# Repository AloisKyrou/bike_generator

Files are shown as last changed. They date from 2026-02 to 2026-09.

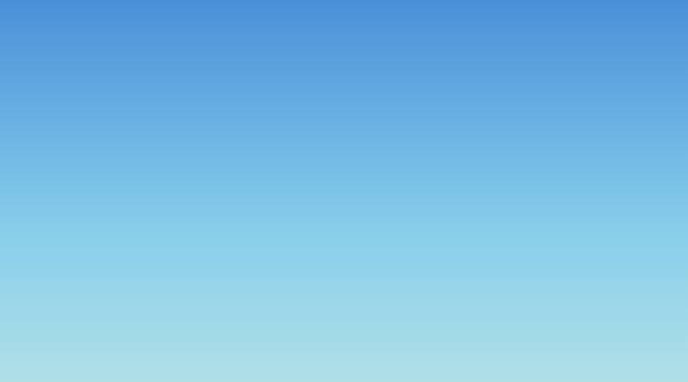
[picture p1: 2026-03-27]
webapp/bike-watts/assets/world/background.png

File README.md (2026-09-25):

# Bike Generator — Smart Trainer

> Turn a scooter motor and a stationary bike into a power-generating trainer that speaks the standard Bluetooth FTMS protocol. Control has been verified with Zwift and TrainerDay; other FTMS applications remain to be tested explicitly.

Project overview placeholder
*Photo placeholder — full system: bike, generator, electronics box, BLUETTI*

---

## What is this?

This project converts human pedaling power into usable electrical energy, while also making the bike behave like a **smart trainer** — the kind you would use with a cycling app like Zwift.

The rider pedals, a scooter motor (used as a generator) produces electricity, a DC/DC converter regulates it to 24V, and a **BLUETTI AC50S** power station charges from it.

At the same time, an **ESP32-C3** microcontroller:
- Measures voltage, current and power on the bus
- Controls pedaling resistance via a digital potentiometer on the DC/DC converter
- Exposes all of this over **Bluetooth** using the standard **FTMS protocol**, so any cycling app can connect and control the trainer

Surplus power that the BLUETTI cannot absorb is burned off by halogen lamp dump loads, which also provide a baseline braking torque.

---

## System Overview

```
[Rider] -> [Motor/Generator] -> [Rectifier] -> [DC/DC Buck 24V] -> [BLUETTI AC50S]
                                                     |
                                               [Dump Load 40-80W]
                                                     |
                                              [ESP32-C3 controller]
                                               measures V, I, P
                                               controls resistance via SPI digipot
                                               streams data over BLE (FTMS)
```

Power path diagram placeholder
*Diagram placeholder — power path schematic*

---

## Features

- **Real power generation** — energy goes into a real battery (BLUETTI AC50S, 500Wh)
- **Standard smart-trainer interface** — verified with Zwift and TrainerDay; designed for other Bluetooth FTMS clients
- **Three control modes:**
  - **Manual** — set resistance level with a physical BLE button or from the app
  - **ERG** — app sets a target wattage, mapped to a calibrated resistance setting (open loop)
  - **Simulation** — app sends road gradient, system adjusts resistance accordingly
- **Live telemetry** — voltage, current, power streamed over BLE at 2 Hz
- **Passive dump load** — permanently connected halogen lamps absorb surplus power and add baseline braking torque
- **Wireless button** — EnOcean PTM215B BLE button for standalone control (no phone needed)

---

## Hardware

| Component | Role |
|---|---|
| Scooter motor | Generator (3-phase AC) |
| 3-phase bridge rectifier | AC to DC |
| 400W CV/CC buck module | Regulated 24V bus and current limit |
| **ESP32-C3** (Beetle) | MCU: sensors, BLE, digipot control |
| **DFR0520** prototype / **MCP4151-104** PCB V1 | Digital potentiometer, sets buck current limit via SPI |
| **ACS712 30A** | Hall-effect current sensor |
| Resistive voltage divider (100k + 7.5k) | Bus voltage measurement, safe across the BLUETTI's 12–40V input range |
| **BLUETTI AC50S** | 500Wh power station, primary load |
| G4 12V/20W halogen bulbs (pairs in series) | Dump load (~40W per pair) |
| EnOcean PTM215B | BLE pushbutton for manual resistance control |

See the **[component references](docs/components/README.md)** for datasheets and product links.

---

## Electronics Box

Electronics box placeholder
*Photo placeholder — inside the electronics enclosure*

The prototype uses an external DFR0520 module. PCB V1 integrates the equivalent
single-channel MCP4151-104 and exposes only `CC_A`, `CC_W` and `CC_B` toward the
buck current-limit potentiometer terminals.

---

## Getting Started

### 1. Hardware assembly

Follow the wiring guide in **[docs/hardware.md](docs/hardware.md)**.

Key points:
- Wire the ACS712 in-line with the bus current path
- Wire the resistive divider (100k + 7.5k) from the bus to GPIO1
- Prototype: wire the DFR0520 as documented. PCB V1: connect only `J_CC_CTRL`
  after validating the buck's A/W/B voltage and current limits.
- Wire halogen pairs (2x G4 12V/20W in series) across the 24V bus

### 2. Configure config.h

Open `config.h` and confirm your values:

```cpp
#define PIN_CURRENT_SENSOR  0       // ACS712 on GPIO0
#define PIN_VOLTAGE_SENSOR  1       // voltage divider on GPIO1

#define POT_CAL_VALUE       30      // wiper position during calibration
#define POT_CAL_POWER       120.0f  // measured watts at that wiper position

#define VDIV_R1_OHMS        100000.0f
#define VDIV_R2_OHMS         7500.0f
```

### 3. Flash the firmware

- Open `bike_generator.ino` in the **Arduino IDE**
- Select board: **ESP32C3 Dev Module**
- Upload and open Serial Monitor at **115200 baud**

You should see:
```
*** READY TO PAIR ***
Device name: 'ESP32 Bike Trainer'
```

### 4. Connect a cycling app

Open Zwift (or any FTMS-compatible app), scan for **"ESP32 Bike Trainer"** and pair it as your controllable trainer and power meter.

App pairing placeholder
*Screenshot placeholder — device pairing in Zwift*

### 5. Ride

Start pedaling. The app displays your live power and controls resistance based on the virtual road. Surplus power charges the BLUETTI.

---

## Calibration

1. Apply a known voltage to the bus (e.g. bench PSU at 24.0V)
2. Read the Serial Monitor: adjust `VDIV_OFFSET_V` if the reported voltage differs from your multimeter
3. Pedal steadily at wiper `POT_CAL_VALUE = 30`, note the stable watt reading, update `POT_CAL_POWER`

Full procedure: **[docs/hardware.md](docs/hardware.md)**

---

## Documentation

| Document | Contents |
|---|---|
| **[docs/build-tutorial.md](docs/build-tutorial.md)** | **Full step-by-step build guide — start here** |
| **[electrical/](electrical/)** | **Electrical engineering workspace, component files and future KiCad project** |
| [docs/ble-api.md](docs/ble-api.md) | BLE API reference for app/game developers |
| [docs/hardware.md](docs/hardware.md) | Power path, wiring, pinout, calibration |
| [docs/electrical/](docs/electrical/) | Electrical analysis and INA228 PCB V1 design dossier |
| [docs/firmware.md](docs/firmware.md) | Code architecture, BLE FTMS, control modes |
| [docs/components/README.md](docs/components/README.md) | Datasheets and product links |
| [docs/pedaling-resistance-physics.md](docs/pedaling-resistance-physics.md) | Why electrical loading creates braking torque, operating regions, and measurement plan |
| [docs/related-projects.md](docs/related-projects.md) | Comparison with ble-ftms, SmartSpin2k, and Gymnasticon |

---

## Safety Notes

- BLUETTI DC input: **12-40V max, 10A max, 120W max** — do not exceed
- Fuse the 24V bus at **10A**
- Halogen lamps get very hot — use a ventilated non-flammable enclosure
- ACS712 must have **no current flowing at boot** for auto-calibration to work
- ESP32-C3 GPIO pins: **3.3V max**

---

## Roadmap

- [ ] Dump load MOSFET switching with soft-start ramp
- [ ] Bus voltage hysteresis loop for dump load control
- [ ] Separate current metering for BLUETTI vs dump load
- [ ] Temperature sensors on buck and rectifier
- [ ] iOS companion app for Wh session tracking

---

## License

[MIT](LICENSE)

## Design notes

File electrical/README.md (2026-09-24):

# Electrical workspace

This directory contains the engineering workspace for the electrical part of
the bike generator. It is kept separate from the firmware, web application and
public build documentation at the repository root.

The KiCad 10 project has been created through Konnect under
[`kicad/bike-generator-controller/`](kicad/bike-generator-controller/). Its
five-sheet functional hierarchy is in place; the component-level design is now
implemented for measurement, control, MCU and low-voltage connectors. The
power path remains deliberately open until its electrical limits are measured.

## Directory map

```text
electrical/
├── components/                 Component references and downloaded datasheets
├── measurements/               Raw measurements, photos and processed results
├── bom/                        Working bills of materials and sourcing notes
└── kicad/
    ├── bike-generator-controller/  KiCad project sources
    ├── libraries/                  Project-owned symbols, footprints and 3D models
    └── exports/                    Generated review/fabrication outputs
```

## Existing design documentation

The current analysis remains in [`docs/electrical/`](../docs/electrical/) so it
stays visible from the main project documentation:

- [Electrical decisions and scope](../docs/electrical/README.md)
- [Observed prototype and open questions](../docs/electrical/as-built-and-open-questions.md)
- [INA228 PCB V1 specification](../docs/electrical/pcb-v1-ina228.md)
- [Measurement campaign](../docs/electrical/measurement-campaign.md)
- [Design methodologies](../docs/electrical/design-methodologies.md)
- [KiCad workflow and troubleshooting](kicad/WORKFLOW.md)
- [Controller V1 working BOM](bom/controller-v1-working.md)

## Working rules

- Component PDFs and manufacturer files belong in `components/`, not beside the
  KiCad sources.
- Raw readings are never overwritten; corrected or transformed data goes into
  `measurements/processed/`.
- Generated Gerbers, PDFs and manufacturing archives belong in
  `kicad/exports/` and are ignored by Git by default.
- KiCad sources will be versioned, but must only be created or changed through
  KiCad/Konnect to preserve their internal references.

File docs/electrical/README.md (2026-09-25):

# Dossier électrique et PCB

Ce dossier rassemble l'état des connaissances électriques du vélo générateur et
prépare une première carte électronique sous KiCad.

Les fichiers de travail, datasheets, mesures et le futur projet KiCad sont
rangés dans l'[espace d'ingénierie électrique](../../electrical/).

Il distingue volontairement :

- le prototype actuellement assemblé sur breadboard ;
- les éléments identifiés mais encore à mesurer ;
- la cible décidée pour le PCB V1 ;
- les améliorations reportées à une révision ultérieure.

## Décision actuelle pour le PCB V1

La première carte utilisera un **INA228AIDGSR soudé directement sur le PCB** avec
une résistance shunt dédiée. Elle ne conservera pas l'ACS712 et le pont diviseur
comme chaîne de mesure principale.

Décisions retenues :

- CAO : KiCad ;
- microcontrôleur : carte DFRobot Beetle ESP32-C3 DFR0868 montée sur connecteurs ;
- mesure : INA228, interface I2C, alimentation logique 3,3 V ;
- shunt V1 : Bourns `CSS4J-4026K-2L00F`, 2 mΩ, quatre bornes, 6 W, avec
  footprint KiCad natif géométriquement compatible ;
- emplacement : conducteur positif, après le redresseur et avant le buck ;
- grandeur mesurée : puissance électrique envoyée par la génératrice au buck ;
- enveloppe de puissance : 400 W, avec 20 A continus et 25 A transitoires comme
  base préliminaire de dimensionnement du chemin cuivre ;
- convertisseur 400 W : conservé comme module externe ;
- sortie du convertisseur principal : 24 V réglé manuellement ; batterie ou
  charge aval laissée hors du périmètre du PCB contrôleur ;
- alimentation autonome : branche auxiliaire prélevée après fusible et shunt,
  avant le buck principal ;
- convertisseur auxiliaire : LM5164 100 V / 1 A pour une sortie 5 V, composants
  périphériques V1 sélectionnés et calcul documenté ;
- batterie contrôleur : LiPo 1S protégée `801350`, 500 mAh, raccordée à la
  broche `BAT` du Beetle par JST-PH ;
- sélection de source : interrupteur batterie et cavalier `JP_GEN_5V` pour
  isoler l'alimentation générateur pendant l'usage USB ;
- commande CC : `MCP4151-104E/SN` simple canal intégré au PCB, après validation
  électrique de l'interface du buck ;
- interface principale : BLE ;
- interface locale : voyants et connecteur I2C pour un écran optionnel ;
- écran : non imposé et non soudé directement sur la V1.

La valeur mesurée avant le buck n'est pas exactement la puissance mécanique aux
pédales. Elle exclut les pertes mécaniques, celles de la génératrice et celles du
redresseur. Elle est toutefois mieux corrélée à l'effort produit que la seule
puissance livrée à la batterie après conversion.

## Ce qui ne fait pas partie de la V1

- recréer le convertisseur CV/CC 400 W sur le PCB ;
- intégrer les composants de puissance du buck ;
- intégrer ou gérer la batterie principale située après la sortie 24 V ;
- réaliser un compteur certifié d'énergie ;
- garantir une estimation exacte de la puissance mécanique du cycliste ;
- intégrer immédiatement un écran couleur ;
- commuter automatiquement les charges de dissipation.

## Documents

| Document | Contenu |
|---|---|
| [État actuel et questions ouvertes](as-built-and-open-questions.md) | Lecture des photos, références probables, incohérences et risques |
| [Spécification du PCB V1](pcb-v1-ina228.md) | Architecture cible, INA228, shunt, connecteurs et coût indicatif |
| [Campagne de mesures](measurement-campaign.md) | Relevés nécessaires avant de figer le schéma |
| [Dimensionnement du chemin de puissance](power-path-dimensioning.md) | Interprétation des mesures, commande CC, composants candidats, batterie et intégration mécanique |
| [Méthodologies de conception](design-methodologies.md) | Manières possibles de démarrer et méthode hybride recommandée |

## Statuts employés

- **observé** : visible sur une photo ou mesuré physiquement ;
- **documenté** : présent dans le code ou un document du dépôt ;
- **probable** : identification forte, mais référence à confirmer ;
- **décidé pour V1** : choix de conception, pas encore réalisé ;
- **bloquant** : information requise avant fabrication.

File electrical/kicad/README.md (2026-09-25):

# KiCad workspace

The KiCad 10 project lives at:

```text
electrical/kicad/bike-generator-controller/
```

The planned project basename is:

```text
bike-generator-controller
```

The project was created and edited through Konnect. It contains the root
schematic, six hierarchical sheets and the initial PCB file for KiCad 10.0:

- `bike-generator-controller.kicad_pro`
- `bike-generator-controller.kicad_sch`
- `bike-generator-controller.kicad_pcb`

## Layout

```text
kicad/
├── bike-generator-controller/  Project sources created by KiCad/Konnect
├── libraries/
│   ├── symbols/                 Project-owned custom symbol libraries
│   ├── footprints/              Project-owned `.pretty` libraries
│   └── 3d-models/               STEP/WRL models owned by the project
└── exports/                     Generated PDFs, Gerbers, drills, BOM and CPL
```

Manufacturer PDFs do not belong here; store them under
[`../components/`](../components/).

## Schematic sheets

The initial schematic hierarchy has been created:

1. `POWER_PATH`
2. `INA228_SENSE`
3. `MCU`
4. `CC_CONTROL`
5. `CONNECTORS`
6. `AUX_SUPPLY`

The root schematic contains these six sheets on pages 2 to 7. `INA228_SENSE`,
`MCU`, `CC_CONTROL`, `CONNECTORS`, `POWER_PATH` and `AUX_SUPPLY` are populated
and linked. `POWER_PATH` contains the 400 W path, the provisional four-wire
shunt, `BUS_PROTECTED`, the external buck connection and the separately fused
auxiliary branch. Its Kelvin and bus outputs feed `INA228_SENSE`, while
`AUX_IN_PROTECTED` feeds the LM5164 sheet.

`AUX_SUPPLY` implements the 5 V supply around the LM5164 for the V1 protected
bus ceiling of 80 V, including UVLO, feedback, Type-3 ripple network,
input/output capacitors, `PGOOD`, a power flag and four test points. Its V1
passives and footprints are selected. The MLCC DC-bias curves are checked;
`C4`, `C5` and the added parallel `C13` are now the selected 10 µF / 100 V
X7S parts in KiCad. The TI/WEBENCH cross-check remains required before ordering.
`AUX_5V` is now connected to the MCU sheet through the manual `JP3`
generator/USB interlock. The global ERC reports exactly one intentional error:
the root-sheet output `AUX_PGOOD` is not yet connected to the future hardware
enable logic. It must not be waived or hidden.

The MCU sheet now assigns two existing KiCad footprints, both still marked
provisional: a 2.54 mm through-hole 1x02 header for `JP3`, and
`Connector_JST:JST_PH_S2B-PH-K_1x02_P2.00mm_Horizontal` for the battery
connector `J6`. `J6.1` is `BAT_RAW` and `J6.2` is `GND`. The real battery plug
pitch, mating orientation and polarity must be checked before PCB release.

Project-owned library items currently include:

- `BikeGenerator:DFR0868_Beetle_ESP32-C3` — symbole de schéma ;
- `BikeGenerator:DFR0868_Beetle_ESP32-C3_V2_Socketed` — empreinte porte-module
  sur deux sockets 1×8, créée depuis le CAD DFRobot V2.0 et affectée à `U2` ;
- `BikeGenerator:DFR0520_Dual_Digital_Pot` — ancien module traversant conservé
  uniquement pour documenter le prototype ; le PCB V1 utilise les bibliothèques
  KiCad natives pour `MCP4151-104E/SN` et son SOIC-8.

See the [KiCad workflow and troubleshooting guide](WORKFLOW.md) for the
creation steps, their manual equivalent and the verification process.
The implementation order and completion gates are tracked in the
[KiCad roadmap](ROADMAP.md).
The latest project-level connectivity evidence is summarized in
[the connection audit](CONNECTION_AUDIT.md).
The active PCB routing classes, their net assignments and their engineering
limits are recorded in [NETCLASSES.md](NETCLASSES.md).

## Source and generated files

Version in Git:

- KiCad project, schematic and PCB sources;
- project-local library tables and custom libraries;
- explicit design-rule files;
- human-written design notes.

Keep outside Git by default:

- lock, autosave and backup files;
- temporary plots;
- generated fabrication outputs under `exports/`.

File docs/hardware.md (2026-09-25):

# Hardware Reference

This document covers the full power path, wiring, pinout and calibration procedure for the bike generator system.

> This page describes the current ACS712-based prototype. The planned KiCad PCB
> V1 replaces the ACS712 and voltage-divider measurement chain with an INA228 and
> a shunt placed before the buck. See the [electrical and PCB dossier](electrical/).

---

## 1. Power Path Overview

```
[Rider pedaling]
      │
      ▼
[Scooter motor used as generator — 3-phase AC]
      │
      ▼
[3-phase bridge rectifier — DC output]
      │
      ▼
[DC/DC Buck module — CV/CC 400W class]
  Sets regulated 24V bus + current limit (= pedaling resistance)
  Current limit driven by DFR0520 (prototype) or MCP4151-104 (PCB V1) via SPI
      │
      ├──────────────────────────────┐
      ▼                              ▼
[BLUETTI AC50S DC input]     [Dump load — halogen lamps G4 12V/20W]
  Up to ~120W charging          Surplus power + baseline braking torque
```

The DC bus nominally runs at **24V**. The BLUETTI is the primary sink (up to ~120W / ~5A). Halogen lamps on the bus act as a permanent dump load to absorb excess power and provide baseline braking torque even when the BLUETTI is not charging.

---

## 2. Component Map & Pinout

### ESP32-C3 (Beetle variant)

| GPIO | Function | Notes |
|---|---|---|
| 0 | ACS712 current sensor (ADC) | `ADC_11db`, 12-bit |
| 1 | Voltage divider (ADC) | `ADC_11db`, 12-bit |
| 4 | Free / extension | No longer used by the PCB V1 digipot |
| 5 | MCP4151 CS | Chip Select, active LOW |
| 6 | MCP4151 SCK | SPI clock |
| 7 | MCP4151 SDI/SDO | Write-only SPI data in PCB V1 |

> ⚠️ ESP32-C3 ADC pins are 3.3V max. Never exceed this voltage on any ADC input.

---

## 3. Current Sensing — ACS712 30A

The ACS712 outputs a voltage proportional to current, centered at Vcc/2 (~1.65V at 3.3V supply) with no current flowing.

**Calibration formula:**
```
I (A) = |V_adc - V_midpoint| / sensitivity
```

- `sensitivity` = 39 mV/A (calibrated; nominal for 30A variant is 66 mV/A — adjust in `config.h`)
- `V_midpoint` is measured at boot with no current flowing (auto-calibration in `Sensors_Calibrate()`)

**Wiring:**
```
Bus current path ──► [IP+] ACS712 [IP-] ──► load
                          │
                        [VIOUT] ──► GPIO0 (ADC)
                        [VCC]  ──► 3.3V
                        [GND]  ──► GND
```

> ⚠️ At boot, make sure no current is flowing through the ACS712. The firmware takes a zero-current baseline for ~1 second during `setup()`.

---

## 4. Voltage Sensing — Resistive Divider

To measure the ~24V bus with the 3.3V ADC, a resistive divider scales the voltage down.

**Circuit:**
```
V_BUS ──[R1 = 100kΩ]──┬──[R2 = 7.5kΩ]── GND
                       └──► GPIO1 (ADC)
```

**Scaling:**
```
V_ADC = V_BUS × R2 / (R1 + R2)
      = V_BUS × 7.5k / 107.5k
      = V_BUS × 0.0698

V_BUS (theoretical ADC limit) = 3.3V / 0.0698 ≈ 47.3V
At the BLUETTI 40V input ceiling, the ADC sees about 2.79V.
```

**To change resistor values:** only edit `VDIV_R1_OHMS` and `VDIV_R2_OHMS` in `config.h`. The scale factor and max voltage are derived automatically.

**Software calibration trim:** after wiring, measure a known voltage on the bus with a multimeter and compare to the serial log output `ADC volt: Vpin=X.XXV → bus=XX.XXV`. Adjust `VDIV_OFFSET_V` by the difference.

---

## 5. Digital Potentiometer — MCP4151-104 (PCB V1)

The breadboard prototype used a DFR0520 breakout containing a dual MCP42100.
PCB V1 replaces it with one `MCP4151-104E/SN`: one 100kΩ channel, 257
positions and a native SOIC-8 footprint. The external `CC_A`, `CC_W` and
`CC_B` behavior remains unchanged.

The single channel is wired into the buck module's CC (constant current)
feedback network. Moving the wiper changes the current limit setpoint and thus
how hard the rider must pedal.

**SPI protocol:**
```
CS LOW → send 0x00 (write volatile wiper 0) → send value (0–255) → CS HIGH
```

The analog compatibility gate remains mandatory: before connecting the buck,
verify that A/W/B always remain between 0 and 3.3V and below 2.5mA.

**Wiper-to-power mapping (linear, single-point calibrated):**
```
wiper = target_power × (POT_CAL_VALUE / POT_CAL_POWER)
      = target_power × (30 / 120)
      = target_power / 4
```

Update `POT_CAL_VALUE` and `POT_CAL_POWER` in `config.h` after measuring your actual system.

**Safe operating ceiling:** `POT_SAFE_MAX = HILL_POWER_TARGET / 4 = 50`. The wiper is never sent above this value, capping bus power at 200W (120W BLUETTI + 2×40W halogen).

---

## 6. Dump Load — G4 Halogen Lamps

**Configuration:** pairs of G4 12V/20W bulbs wired **in series** across the 24V bus.

```
24V bus ──[bulb A 12V/20W]──[bulb B 12V/20W]── GND
```

Each pair dissipates ~40W at 24V (once filaments are hot). Multiple pairs can be wired in parallel to increase dump power in ~40W steps.

| Pairs | Dump power |
|---|---|
| 1 | ~40W |
| 2 | ~80W |
| 3 | ~120W |

> ⚠️ Cold filament resistance is much lower than hot — expect inrush current spikes when switching lamps. The lamps get very hot; ensure ventilation and keep away from plastics.

---

## 7. BLUETTI AC50S DC Input

- Input range: **12–40V OCV**
- Max current: **10A**
- Max power: **120W**

At 24V, the BLUETTI will absorb up to ~5A. If the generator produces more than 120W, the surplus must go to the dump load to prevent bus overvoltage.

**DC input connector:** XT60 or barrel (check your unit). Wire bus positive/negative with correct polarity — there is no reverse polarity protection on the BLUETTI input.

---

## 8. Wiring Safety Checklist

- [ ] Fuse the bus at 10A (protects BLUETTI and wiring)
- [ ] ACS712 in the current path — rated 30A, continuous
- [ ] Resistor divider: R1/R2 must be rated for the voltage (standard ¼W fine for voltage sensing only)
- [ ] Halogen lamps: mounted on ceramic/metal base, ventilated enclosure
- [ ] Buck module: heatsink + airflow for sustained operation
- [ ] All high-current connections: short, thick wire (≥ 1.5mm² / AWG14 for bus)
- [ ] ESP32-C3 powered from 3.3V regulated supply — not directly from 24V bus

---

## 9. Calibration Procedure (First Boot)

1. **Do not connect the bus / generator yet.**
2. Flash the firmware, open Serial Monitor at 115200 baud.
3. Power the ESP32-C3 from USB only. Observe the ACS712 midpoint calibration log:
   ```
   [SENSORS] ACS712 midpoint: 1650 mV (1.650V)
   ```
4. Connect the voltage divider to a known reference (e.g. bench PSU at 24.0V).
5. Observe the serial log:
   ```
   ADC volt: Vpin=1.674V → bus=24.0V (divider x14.33)
   ```
   If the bus reading differs from your multimeter, adjust `VDIV_OFFSET_V` in `config.h`.
6. Connect the full system and verify power readings at a steady pedaling effort.
7. Update `POT_CAL_VALUE` and `POT_CAL_POWER` in `config.h` with your measured wiper/power pair.

---

*See also: [Firmware Architecture](firmware.md) · [Component References](components/)*

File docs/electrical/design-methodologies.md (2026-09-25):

# Méthodologies possibles pour démarrer le PCB

Plusieurs méthodes sont raisonnables. Elles diffèrent surtout par la quantité de
mesures effectuées avant le premier schéma et par le risque accepté sur la
première fabrication.

## Méthode A — recopier et fiabiliser le prototype

1. Relever fil par fil la breadboard.
2. Dessiner le schéma « tel que construit ».
3. Remplacer ACS712 et pont diviseur par INA228 + shunt.
4. Ajouter connecteurs, protections et points de test.
5. Router puis fabriquer.

**Atout :** passage très direct du montage qui fonctionne vers une carte.

**Limite :** les erreurs et hypothèses implicites du prototype risquent d'être
reproduites. L'interface CC à deux fils doit impérativement être comprise avant
le routage.

## Méthode B — partir des exigences et des fiches techniques

1. Fixer tensions, courants, température, environnement et état sûr.
2. Dessiner l'architecture fonctionnelle cible.
3. Concevoir chaque sous-circuit depuis la fiche de son fabricant.
4. Définir les interfaces avec le buck et les modules existants.
5. Vérifier le résultat sur le prototype avant fabrication.

**Atout :** schéma plus propre, justifiable et reproductible.

**Limite :** risque de concevoir autour de valeurs théoriques qui ne décrivent
pas parfaitement le matériel déjà possédé.

## Méthode C — tester d'abord le INA228 sur une carte d'évaluation

1. Acheter ou assembler un petit module INA228.
2. Le connecter temporairement avant le buck avec un shunt adapté.
3. Valider les lectures I2C et comparer avec le multimètre.
4. Copier le sous-circuit validé dans le PCB définitif.

**Atout :** réduit fortement le risque lié au capteur et permet d'écrire le
pilote avant la réception du PCB.

**Limite :** coût et étape supplémentaires ; les performances du module ne
garantissent pas celles du routage final.

## Méthode D — carte porte-modules minimale

1. Conserver le Beetle sur connecteurs et intégrer le MCP4151 simple canal.
2. Intégrer INA228, shunt, alimentation, protections et connectique.
3. Garder le buck, le redresseur et les charges externes.
4. Prévoir beaucoup de points de test et d'options non montées.

**Atout :** excellente première carte : utile, réparable et d'une complexité
raisonnable.

**Limite :** moins compacte qu'une intégration complète et dépend encore des
modules du commerce.

## Méthode recommandée — hybride par jalons

La meilleure approche pour ce projet combine B, C et D :

### Jalon 1 — caractériser

- effectuer la campagne de mesures ;
- figer tension maximale, courant cible et stratégie de masse ;
- caractériser précisément le réglage CC.

**Sortie :** tableau de mesures complet et aucune interface électrique inconnue.

### Jalon 2 — schéma fonctionnel KiCad

- créer les feuilles `POWER_PATH`, `INA228_SENSE`, `MCU`, `CC_CONTROL` et
  `CONNECTORS` ; le bloc auxiliaire LM5164 reste dans `POWER_PATH` pour garder
  l'origine de son énergie et les protections de bus sur une même feuille ;
- représenter le buck et le redresseur comme blocs externes connectés ;
- inscrire sur le schéma les limites de tension et courant de chaque liaison.

**Sortie :** schéma lisible indépendamment du PCB et nomenclature préliminaire.

### Jalon 3 — preuve de mesure

- tester un INA228 sur module d'évaluation si disponible, ou réaliser d'abord le
  sous-circuit sur une petite carte d'essai ;
- écrire un pilote minimal : identité, tension, courant, puissance et alerte ;
- comparer avec un multimètre et une charge connue.

**Sortie :** valeurs cohérentes et constante de shunt validée.

### Jalon 4 — schéma électrique complet

- intégrer l'alimentation auxiliaire LM5164, la batterie contrôleur,
  `JP_GEN_5V`, les protections, INA228, Beetle, MCP4151 et connecteurs ;
- définir l'état sûr au reset ;
- exécuter l'ERC et justifier explicitement chaque exception.

**Sortie :** revue de schéma validée avant tout routage.

### Jalon 5 — placement et routage

- placer d'abord shunt, connecteurs de puissance et INA228 ;
- router la puissance puis les paires Kelvin ;
- séparer les retours bruyants du buck de la mesure ;
- placer découplages et protections au plus près ;
- terminer par SPI, I2C, voyants et écran optionnel.

**Sortie :** DRC propre, analyse thermique et contrôle des largeurs de piste.

### Jalon 6 — fabrication et bring-up

1. vérifier les courts-circuits sans composants de puissance connectés ;
2. alimenter la logique avec une alimentation limitée en courant ;
3. vérifier 3,3 V et communication I2C ;
4. injecter 10 V sur l'entrée auxiliaire, vérifier 5 V, `PGOOD` et l'absence de
   retour de courant ;
5. valider la bascule entre alimentation générateur et batterie ;
6. tester avec une charge limitée ;
7. intégrer progressivement redresseur, buck, charges puis stockage externe.

**Sortie :** rapport de bring-up et liste des corrections pour V1.1.

## Pourquoi cette méthode convient ici

Elle permet d'apprendre une vraie conception électronique — schéma, composants
CMS, mesure analogique, puissance, implantation et firmware — sans faire du
convertisseur 400 W lui-même le premier exercice. Les modules qui fonctionnent
déjà restent remplaçables, tandis que la partie nouvelle et structurante,
l'INA228 et son shunt, est réellement intégrée au PCB.

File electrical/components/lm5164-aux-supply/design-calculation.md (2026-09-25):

# Pré-dimensionnement LM5164 — bus protégé jusqu'à 80 V vers 5 V

Statut : **base de calcul pour le schéma, pas encore une nomenclature prête à
commander**.

Ce document applique les équations de la fiche TI `SNVSAU4D`, révision D de
février 2026, archivée dans ce dossier. Les numéros de pages ci-dessous sont les
pages du PDF.

## Hypothèses V1

| Paramètre | Valeur de calcul | Commentaire |
|---|---:|---|
| Plage vérifiée | 10 à 80 V DC | bus protégé ; démarrage UVLO nominal vers 9 V |
| Plafond de bus | 80 V DC continu, transitoires tolérés compris | fonctionnement durable au-dessus hors spécification |
| Sortie | 5 V | vers l'entrée 5 V du contrôleur |
| Charge continue attendue | 600 mA | ESP32, capteurs et recharge de la batterie |
| Charge de dimensionnement | 1 A | marge pour recharge et pointes radio |
| Fréquence visée | environ 300 kHz | compromis taille, rendement et pertes |
| Ondulation d'inductance visée | environ 30 % à 50 % à 1 A | recommandation TI |
| Méthode d'injection d'ondulation | type 3 | faible ondulation de sortie |

La tension nominale réelle du bus dépendra de la vitesse de pédalage. Les
calculs sont donc vérifiés à 10, 24, 36, 60 et 80 V plutôt qu'à un seul point.

## Valeurs V1 et choix encore ouverts

| Fonction | Valeur / référence | Statut |
|---|---:|---|
| `RRON` | Yageo `RC1206FR-0741K2L`, 41,2 kΩ, 1 %, 250 mW | choix V1 figé |
| `L` | Coilcraft `MSS1038-473MLC`, 47 µH ±20 % | choix V1 validé |
| `RFB1` haut | Yageo `RT0805BRD07316KL`, 316 kΩ, 0,1 % | choix V1 figé |
| `RFB2` bas | Yageo `RT0805BRD07100KL`, 100 kΩ, 0,1 % | choix V1 figé |
| `RA` | Yageo `RC0805FR-07200KL`, 200 kΩ, 1 % | choix V1 figé |
| `CA` | Yageo `CC0805KRX7R9BB332`, 3,3 nF, 50 V, X7R | choix V1 figé |
| `CB` | Yageo `CC0805JRNPO9BN820`, 82 pF, 50 V, C0G/NP0 | choix V1 figé |
| `CBST` | Yageo `CC0805KRX7R9BB222`, 2,2 nF, 50 V, X7R | choix V1 figé |
| `COUT` | 2 × Samsung `CL32B226KOJNNNE`, 22 µF, 16 V, X7R | choix V1 figé ; environ 33,7 µF effectifs au total à 5 V et 25 °C |
| `CIN` HF | 3 × Samsung `CL32Y106KCVZ4NE`, 10 µF, 100 V, X7S | choix V1 corrigé après lecture de la courbe DC-bias à 80 V |
| `CIN` amortissement | environ 10 µF électrolytique, tension adaptée | candidat si câblage d'entrée long |
| `RUV1` | Yageo `RC0805FR-071ML`, 1 MΩ, 1 % | choix V1 figé |
| `RUV2` | Yageo `RC0805FR-07200KL`, 200 kΩ, 1 % | choix V1 figé |
| Pull-up `PGOOD` | Yageo `RC0805FR-0747KL`, 47 kΩ, 1 % | choix V1 figé |

`F_AUX` est figé à 1 A / 125 V. Seule la TVS reste source-spécifique et dépend
des mesures de la génératrice.
Le condensateur d'amortissement est le Panasonic `EEU-FC2A100`, 10 µF / 100 V.

## Fréquence et résistance `RON`

La fiche TI donne, équations 12 et 15, page PDF 17 :

```text
RRON[kΩ] = VOUT[V] × 2500 / FSW[kHz]
```

Pour 5 V et 300 kHz, la valeur théorique est 41,67 kΩ. La valeur E96 de
41,2 kΩ donne environ 303 kHz. La durée de conduction calculée avec l'équation
11 reste comprise entre 1,648 µs à 10 V et 0,206 µs à 80 V, très au-dessus du
minimum contrôlable de 50 ns.

À 80 V, la résistance voit environ 79 V puisque la broche RON est voisine de
1 V. Sa dissipation est donc d'environ 151 mW. Le passage du boîtier 0805
125 mW au `RC1206FR-0741K2L` 250 mW est nécessaire ; il laisse environ 40 % de
marge à température ambiante. Le déclassement thermique devra encore être
contrôlé avec la température réelle de la carte.

## Inductance

Les équations 18 à 20, page PDF 18, donnent :

```text
ΔIL = VOUT / (FSW × L) × (1 − VOUT / VIN)
IL_peak = IOUT_max + ΔIL / 2
```

Avec 47 µH et un calcul conservateur à 300 kHz :

| `VIN` | `tON` | `ΔIL` | Pic à 1 A |
|---:|---:|---:|---:|
| 10 V | 1,648 µs | 0,177 A | 1,089 A |
| 24 V | 0,687 µs | 0,281 A | 1,140 A |
| 36 V | 0,458 µs | 0,305 A | 1,153 A |
| 60 V | 0,275 µs | 0,325 A | 1,163 A |
| 80 V | 0,206 µs | 0,332 A | 1,166 A |

La limite de courant de crête minimale spécifiée est 1,25 A et sa valeur
maximale 1,75 A, page PDF 6. Une inductance de 47 µH conserve plus de marge
qu'une 33 ou 39 µH lorsque sa tolérance et sa baisse à chaud sont prises en
compte. La référence V1 retenue est la Coilcraft `MSS1038-473MLC` : DCR maximale
128 mΩ, courant de saturation 1,6 A à −10 %, 1,98 A à −20 % et 2,22 A à −30 %,
et courant thermique 1,45 A pour une élévation de 20 °C. Elle couvre donc le
pic calculé de 1,166 A et reste exploitable face à la limite haute de 1,75 A du
LM5164.

Critères conservés pour une éventuelle substitution :

- courant de saturation supérieur à 1,75 A, avec une préférence autour de 2 A
  ou davantage ;
- courant thermique efficace compatible avec 1 A continu ;
- valeur encore suffisante à chaud et sous courant ;
- pertes cuivre et noyau vérifiées vers 300 kHz.

L'empreinte standard retenue est
`Inductor_SMD:L_Coilcraft_MSS1038-XXX`. La Bourns `SRP1038C-470M`, également
couverte par une empreinte KiCad standard, reste une option de réduction de
coût à réévaluer, mais son statut « not recommended for new designs » empêche
de la retenir comme référence V1.

## Retour 5 V

L'équation 10, page PDF 12, donne :

```text
RFB2 = 1,2 V / (VOUT − 1,2 V) × RFB1
```

Avec `RFB1 = 316 kΩ` entre la sortie et FB et `RFB2 = 100 kΩ` entre FB et GND,
la consigne nominale vaut 4,992 V. En combinant les limites de la référence
interne TI et les tolérances des résistances :

- résistances 1 % : environ 4,839 à 5,145 V ;
- résistances 0,1 % : environ 4,906 à 5,075 V.

Le 0,1 % est donc préféré. La compatibilité de cette plage avec l'entrée 5 V et
le chargeur du Beetle doit encore être confirmée sur le schéma exact de sa
révision.

## Réseau d'ondulation type 3

Le LM5164 utilise une commande COT et demande une ondulation en phase d'au
moins 20 mV au point typique, avec au moins 12 mV à l'entrée minimale. Les
équations 24 à 26 sont détaillées pages PDF 18 et 19.

Avec `RFB1 = 316 kΩ`, `RFB2 = 100 kΩ` et 300 kHz :

- la capacité `CA` minimale calculée est environ 439 pF ;
- `CA = 3,3 nF` maintient `RA` dans une plage pratique ;
- `RA = 200 kΩ` donne environ 12,5 mV à 10 V, 19,8 mV à 24 V et
  22,9 mV à 60 V, puis 23,4 mV à 80 V ;
- pour un objectif de stabilisation de 75 µs, `CB` calculé vaut environ 79 pF,
  d'où la valeur standard 82 pF en C0G/NP0.

Ces valeurs doivent encore être vérifiées dans le calculateur LM5164 de TI et
sur prototype. Le nœud FB devra rester très court et éloigné de `SW`.

## Condensateurs

### Sortie

L'équation 21 limite l'ondulation capacitive à 0,5 % de 5 V, soit 25 mV. Avec
47 µH, la capacité effective minimale calculée varie d'environ 3,0 µF à 10 V
d'entrée à 5,5 µF à 80 V. La courbe Samsung indique −23,41 % à 5 V : deux
condensateurs de 22 µF donnent environ 33,7 µF effectifs au total à 25 °C,
avant tolérance et température. La marge reste très supérieure au minimum
calculé.

### Entrée

TI impose au moins 2,2 µF de céramique haute fréquence près de VIN et GND.
Les deux MLCC initialement choisis (`CL32B225KCJSNNE`, 2,2 µF / 100 V) ne sont
pas conservés : la courbe Samsung indique −76,58 % à 80 V, soit seulement
1,03 µF effectif au total. La V1 emploie trois `CL32Y106KCVZ4NE`, 10 µF /
100 V, X7S. La courbe fabricant indique −86,06 % à 80 V, soit environ 4,18 µF
pour trois pièces à 25 °C. Après une estimation conservatrice ajoutant la
tolérance −10 % et la variation X7S −22 %, il reste environ 2,94 µF, au-dessus
du minimum TI de 2,2 µF. Les données brutes sont archivées dans
`../controller-passives-v1/` ; cette estimation devra encore être confirmée
sur prototype. La protection doit empêcher que les transitoires tolérés
dépassent eux aussi le plafond de 80 V ; une simple TVS parallèle ne peut pas
le garantir universellement avec seulement 5 V de marge jusqu'à l'INA228.

La fiche recommande aussi environ 10 µF électrolytique avec ESR modéré lorsque
la source est éloignée de plus de 5 cm, afin d'amortir la résonance formée par
les câbles et les céramiques. Le vélo entre clairement dans ce cas probable.

## Démarrage `EN/UVLO`

Les équations 13 et 14, page PDF 14, donnent les seuils de démarrage et d'arrêt.
Avec `RUV1 = 1 MΩ` et `RUV2 = 200 kΩ` :

- démarrage nominal : 9,0 V ;
- arrêt nominal : 8,4 V ;
- avec seuils TI et résistances 1 %, démarrage approximatif entre 8,56 et
  9,46 V, arrêt entre 7,97 et 8,79 V.

Le convertisseur est ainsi démarré avant 10 V dans le pire cas estimé, tout en
restant au-dessus de sa limite fonctionnelle minimale de 6 V. Ce choix devra
être testé sur une montée lente de la génératrice pour vérifier l'absence de
cycles marche/arrêt gênants.

## Contraintes de placement à reporter au PCB

- `CIN` au plus près des pins VIN, GND et du pad exposé ;
- boucle `VIN → MOSFET interne → SW → retour CIN` minimale ;
- `CBST` directement entre BST et SW ;
- inductance collée au nœud SW, avec surface SW minimale ;
- `RRON`, diviseur FB et réseau type 3 proches du circuit ;
- masse analogique des réseaux FB, RON et UVLO ramenée sans courant commuté ;
- pad exposé 9 relié à GND avec la variante locale V1 à six vias thermiques
  Ø0,60/0,30 mm ; anneau de 0,15 mm et traitement des vias sous pad à confirmer
  avec le fabricant ;
- éloigner les pistes Kelvin INA228, l'antenne ESP32 et les signaux numériques
  du nœud SW.

## Vérifications avant placement définitif

1. Rejouer le calcul avec le calculateur officiel LM5164 ou WEBENCH.
2. Les références de CIN, COUT, C6, des résistances et de L1 sont figées pour
   la V1.
3. Vérifier courant d'ondulation, saturation et pertes ; les capacités
   effectives des MLCC sont désormais calculées depuis les courbes Samsung.
4. Mesurer les pics, leur durée et l'impédance de source, puis choisir la TVS
   spécifique à cette source et confirmer `F_AUX`.
5. Confirmer le schéma d'alimentation interne du Beetle et l'absence de retour
   vers l'USB.
6. Prototyper avec une alimentation de laboratoire limitée en courant avant la
   génératrice.

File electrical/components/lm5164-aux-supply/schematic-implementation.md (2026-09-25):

# LM5164 — première implémentation schématique

Date de contrôle : 24 septembre 2026.

Cette note décrit l'état réellement enregistré dans la feuille KiCad
`electrical/kicad/bike-generator-controller/aux_supply.kicad_sch`. Il s'agit
d'une première passe calculée et vérifiable, pas encore d'une nomenclature de
fabrication.

## Interface de la feuille

| Signal | Direction | Rôle |
|---|---|---|
| `AUX_IN_PROTECTED` | entrée | Bus redressé protégé provenant de `POWER_PATH` |
| `AUX_5V` | sortie | Alimentation 5 V auxiliaire |
| `AUX_PGOOD` | sortie | Indication power-good du LM5164 |

La branche d'entrée porte un `PWR_FLAG` parce que la source est externe à la
feuille. `AUX_5V` est maintenant raccordé à la feuille `MCU` ; `AUX_PGOOD`
reste volontairement sans consommateur jusqu'à la conception du verrouillage
matériel de la commande CC.

## Brochage de U4 relu dans la netlist

| Broche | Nom TI | Net KiCad |
|---:|---|---|
| 1 | GND | `GND` |
| 2 | VIN | `AUX_IN_PROTECTED` |
| 3 | EN/UVLO | `UVLO` |
| 4 | RON | `RON_SET` |
| 5 | FB | `FB` |
| 6 | PGOOD | `AUX_PGOOD` |
| 7 | BST | `BST` |
| 8 | SW | `SW` |
| 9 | EP | `GND` |

## Valeurs placées

| Référence | Valeur schématique | Fonction | Statut |
|---|---:|---|---|
| U4 | LM5164DDAT | Buck synchrone 100 V | Référence retenue |
| L1 | Coilcraft `MSS1038-473MLC`, 47 µH ±20 % | Stockage d'énergie | Validée pour la V1 ; `Inductor_SMD:L_Coilcraft_MSS1038-XXX` |
| R8 | 41,2 kΩ, 1 % | Réglage `RON` | Yageo `RC1206FR-0741K2L`, 250 mW, 1206 HandSolder, figée V1 |
| R9 / R10 | 1 MΩ / 200 kΩ, 1 % | Seuil `EN/UVLO` | Yageo `RC0805FR-071ML` / `RC0805FR-07200KL`, figées V1 |
| R11 / R12 | 316 kΩ / 100 kΩ, 0,1 % | Retour 5 V | Yageo `RT0805BRD07316KL` / `RT0805BRD07100KL`, figées V1 |
| R13 | 200 kΩ, 1 % | Injection d'ondulation | Yageo `RC0805FR-07200KL`, figée V1 |
| R14 | 47 kΩ, 1 % | Pull-up `PGOOD` vers 3,3 V | Yageo `RC0805FR-0747KL`, figée V1 |
| C4 / C5 / C13 | 10 µF, 100 V, X7S | Découplage d'entrée | Samsung `CL32Y106KCVZ4NE` ; trois pièces requises par la capacité effective à 80 V, transcrites et raccordées dans KiCad |
| C6 | 10 µF / 100 V | Réservoir d'entrée | Panasonic `EEU-FC2A100`, `Capacitor_THT:CP_Radial_D6.3mm_P2.50mm`, figé V1 |
| C7 / C8 | 22 µF, 16 V | Filtrage de sortie | Samsung `CL32B226KOJNNNE`, figées V1 |
| C9 | 2,2 nF, 50 V | Bootstrap | Yageo `CC0805KRX7R9BB222`, figée V1 |
| C10 | 3,3 nF, 50 V | Condensateur `CA` Type-3 | Yageo `CC0805KRX7R9BB332`, figée V1 |
| C11 | 82 pF, 50 V, C0G | Condensateur `CB` Type-3 | Yageo `CC0805JRNPO9BN820`, figée V1 |

Les résistances et les petits condensateurs utilisent les empreintes KiCad
standard 0805 HandSolder, sauf R8 en 1206 HandSolder pour sa dissipation à
80 V. Les MLCC d'entrée et de sortie utilisent la 1210
HandSolder. `C6` emploie une empreinte traversante native KiCad. Aucun modèle
personnalisé n'a été créé pour ces passifs.

## Topologie du réseau Type-3

Le réseau d'ondulation suit la topologie de la fiche TI :

```text
SW -- R13 -- RIPPLE -- C10 -- AUX_5V
               |
              C11
               |
               FB
```

`C9` relie `BST` à `SW`. L1 relie `SW` à `AUX_5V`. Le pont R11/R12 relie
`AUX_5V`, `FB` et `GND`.

## Contrôles effectués avec Konnect

- neuf broches de U4 reliées aux nets attendus ;
- zéro élément orphelin ;
- zéro court-circuit entre noms de nets ;
- zéro chevauchement de symboles détecté ;
- une seule alerte de net à une broche dans la feuille : `+3V3`, classée
  `cross_sheet_unverified`, ce qui est normal pour le pull-up global de R14 ;
- ERC global après raccordement MCU : zéro avertissement et une erreur
  intentionnelle, `AUX_PGOOD` non raccordé sur la feuille racine.

Cette erreur reste visible jusqu'à la conception du verrouillage matériel de
la commande CC. Elle ne doit pas être supprimée avec un marqueur d'exclusion
ou une connexion factice.

## Travail restant avant gel complet de la feuille

1. Rejouer le dimensionnement dans TI/WEBENCH.
2. Les passifs et L1 sont figés pour la V1 ; vérifier leurs limites thermiques
   dans le prototype.
3. Confirmer sur prototype la température des trois condensateurs d'entrée
   désormais corrigés dans KiCad d'après les courbes Samsung.
4. Vérifier le courant de saturation et les pertes de L1.
5. Fixer fréquence, courant cible et comportement à faible charge.
6. Confirmer avec le fabricant l'anneau de 0,15 mm et le traitement des six
   vias thermiques Ø0,60/0,30 mm de la variante locale affectée à U4.
7. Concevoir l'utilisation matérielle de `AUX_PGOOD`.

Source de topologie et de brochage :
[Texas Instruments, fiche LM5164 SNVSAU4D](https://www.ti.com/lit/ds/symlink/lm5164.pdf).

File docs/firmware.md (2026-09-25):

# Firmware Architecture

The firmware runs on an **ESP32-C3** using the Arduino framework. It is split into small, focused modules — each with a `.h` interface and `.cpp` implementation.

---

## 1. File Map

```
bike_generator/
├── bike_generator.ino      Main entry point (setup / loop)
├── config.h                All constants, pins, calibration values
│
├── hardware.cpp/h          ADC + SPI peripheral setup
├── sensors.cpp/h           ACS712 current + voltage divider reading
├── resistance.cpp/h        MCP4151-104 digital potentiometer control
├── physics.cpp/h           Speed & cadence simulation
├── control_modes.cpp/h     Manual / ERG / Simulation mode state machine
├── ble_ftms.cpp/h          BLE FTMS GATT service (server)
├── button_scanner.cpp/h    BLE central: EnOcean PTM215B button scanner
└── utils.cpp/h             ADC averaging, low-pass filter, map helpers
```

---

## 2. Module Responsibilities

### `config.h`
Central header included by all modules. Defines:
- GPIO pin numbers
- Sensor calibration constants (`ACS712_SENSITIVITY`, `VDIV_R1_OHMS`, etc.)
- Digipot calibration and safe range (`POT_CAL_VALUE`, `POT_SAFE_MAX`)
- Physics tuning parameters
- BLE UUIDs and FTMS flags
- Timing constants

**This is the only file you should need to edit for hardware changes or recalibration.**

---

### `hardware.cpp`
Initialises ADC resolution (12-bit) and pin attenuation (`ADC_11db` = 0–3.3V range) for both sensor pins, and sets up the SPI bus for the digipot.

Called once from `setup()`.

---

### `sensors.cpp`
Reads the two ADC sensors and computes bus power.

| Function | Description |
|---|---|
| `Sensors_Init()` | Runs `Sensors_Calibrate()` to zero the ACS712 baseline |
| `Sensors_Calibrate()` | Averages 8192 ADC samples at no-load to set midpoint |
| `Sensors_ReadCurrent()` | Returns current (A) from ACS712 |
| `Sensors_ReadVoltage()` | Returns bus voltage (V) from resistive divider |
| `Sensors_Update()` | Calls both reads, computes `power = V × I` |
| `Sensors_GetAll()` | Returns full `SensorData` struct (V, I, P, debug ADC values) |

**`SensorData` struct:**
```cpp
typedef struct {
  float voltage;               // Bus voltage (V)
  float current;               // Bus current (A)
  float power;                 // Bus power (W)
  int   rawADC;                // Raw ADC count — current sensor (debug)
  float adcVoltage;            // ADC pin voltage — current sensor (V, debug)
  float adcVoltageDivider;     // ADC pin voltage — voltage divider (V, debug)
} SensorData;
```

---

### `resistance.cpp`
Translates a target power or resistance level into a wiper position and writes
it to the PCB V1 `MCP4151-104` via write-only SPI. The original breadboard used
a DFR0520/MCP42100 module.

**Wiper mapping (linear through origin):**
```
wiper = target_power × (POT_CAL_VALUE / POT_CAL_POWER)
```

| Function | Description |
|---|---|
| `Resistance_Set(value, reason)` | Write wiper directly, clamped to `[POT_MIN, POT_SAFE_MAX]` |
| `Resistance_Increase()` | +1 step (button press) |
| `Resistance_Decrease()` | −1 step (button press) |
| `Resistance_SetFromPower(W)` | Used by ERG mode |
| `Resistance_SetFromGrade(%)` | Used by Simulation mode |
| `Resistance_SetFromLevel(0–100)` | Used by Manual mode |

---

### `physics.cpp`
Computes simulated speed and cadence from measured power. These values are sent to the cycling app via BLE — the app uses them to animate the rider and compute gradient effects on screen.

- **Speed:** solves `P = (Crr·m·g + m·g·grade + ½·ρ·CdA·v²)·v` with Newton's method, capped at 70 km/h
- **Cadence:** piecewise linear target derived from power, with exponential smoothing and ±2 RPM noise

> These are *simulated* values — there is no actual wheel speed or crank sensor. The speed equation is physically motivated, but its input power is electrical bus output rather than measured crank power. Cadence is heuristic. Neither value should be presented as a sensor measurement.

---

### `control_modes.cpp`
State machine with three modes, set by the connected app (or physical button when disconnected):

| Mode | Trigger | Behaviour |
|---|---|---|
| `MODE_MANUAL` | Button press or FTMS opcode `0x04` | Direct resistance level (0–100) |
| `MODE_ERG` | FTMS opcode `0x05` | Hold a target power (W) — open loop |
| `MODE_SIMULATION` | FTMS opcode `0x11` | Set resistance proportional to slope gradient (%) |

`ControlMode_UpdateResistance()` is called every 100ms when an app is connected, dispatching to the appropriate `Resistance_SetFrom*()` call.

---

### `ble_ftms.cpp`
Implements the **Bluetooth FTMS (Fitness Machine Service, UUID 0x1826)** GATT server. The device has been recognised and controlled by **Zwift and TrainerDay**. The standard is intended to enable other FTMS clients as well, but compatibility should be recorded as tested rather than assumed for each application.

**Characteristics exposed:**

| UUID | Name | Properties | Notes |
|---|---|---|---|
| 0x2ACC | Fitness Machine Feature | Read | Reports supported features |
| 0x2AD2 | Indoor Bike Data | Notify | Speed + Cadence + Power @ 2Hz |
| 0x2AD6 | Supported Resistance Range | Read | 0–100, step 1 |
| 0x2AD8 | Supported Power Range | Read | 0–200W, step 1 |
| 0x2AD9 | Fitness Machine Control Point | Write + Indicate | Receives mode/target commands |
| 0x2ADA | Fitness Machine Status | Notify | Status echoes |

**Indoor Bike Data packet** (flags = `0x0024`):
```
[flags 2B][speed 2B][cadence 2B][power 2B]  = 8 bytes
```

**Supported FTMS opcodes:**

| Opcode | Name |
|---|---|
| `0x00` | Request Control |
| `0x01` | Reset |
| `0x04` | Set Target Resistance Level → `MODE_MANUAL` |
| `0x05` | Set Target Power → `MODE_ERG` |
| `0x07` | Start / Resume |
| `0x08` | Stop / Pause |
| `0x11` | Indoor Bike Simulation Parameters → `MODE_SIMULATION` |

---

### `button_scanner.cpp`
While no app is connected, the ESP32-C3 runs as a **BLE central** and scans for advertisement packets from a specific **EnOcean PTM215B** Bluetooth button (identified by MAC address).

On button press, the manufacturer data byte is decoded and `Resistance_Increase()` or `Resistance_Decrease()` is called.

> When an app connects (FTMS server role), button scanning is stopped to free the radio. It resumes automatically on disconnect.

**To change the target button:** update `ENOCEAN_MAC_0` through `ENOCEAN_MAC_5` in `config.h`.

---

### `utils.cpp`
Shared helpers:

| Function | Description |
|---|---|
| `Utils_ReadMilliVoltsAvg(pin, N)` | Average N ADC readings in mV |
| `Utils_LowPassFilter(in, out, α)` | IIR low-pass: `out + α(in − out)` |
| `Utils_MapFloat(x, ...)` | Float version of Arduino `map()` |
| `Utils_Constrain(val, min, max)` | Float constrain |

---

## 3. Main Loop Flow

```
loop()
  │
  ├─ FTMS_HandleConnectionChange()    handle connect/disconnect, restart advertising
  │
  ├─ [if connected]
  │     ButtonScanner_Stop()
  │
  ├─ [if disconnected]
  │     ButtonScanner_Update()        poll EnOcean scan results, restart scan if needed
  │
  ├─ updateBikeData()                 every 100ms:
  │     Sensors_Update()              → read V, I, compute P
  │     ControlMode_UpdateResistance() → write digipot if connected
  │     Physics_CalculateSpeed()
  │     Physics_CalculateCadence()
  │
  ├─ [if connected, every 500ms]
  │     FTMS_SendBikeData()           → BLE notify Indoor Bike Data
  │
  └─ logStatus()                      every 10s: full status dump to Serial
```

---

## 4. Timing Constants (config.h)

| Constant | Default | Description |
|---|---|---|
| `BIKE_DATA_UPDATE_MS` | 100ms | Sensor read + digipot update rate |
| `BLE_NOTIFY_INTERVAL_MS` | 500ms | BLE notification rate (2Hz) |
| `STATUS_LOG_INTERVAL_MS` | 10000ms | Serial status dump interval |
| `SCAN_RESTART_INTERVAL_MS` | 1000ms | Button scanner restart period |

---

## 5. Adding a New Control Mode

1. Add a new value to the `ControlMode` enum in `control_modes.h`
2. Add a handler function `ControlMode_HandleXxx()` in `control_modes.cpp`
3. Add a case in `ControlMode_UpdateResistance()` dispatching to the correct `Resistance_SetFrom*()` call
4. If triggered via BLE, add the corresponding opcode handler in `ble_ftms.cpp`'s `FitnessMachineControlPointCallbacks::onWrite()`

---

*See also: [Hardware Reference](hardware.md) · [Component References](components/)*

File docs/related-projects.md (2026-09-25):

# Related Open Smart-Trainer Projects

Reviewed 2026-09-23 from the projects' own repositories and documentation.

The three projects below overlap with the bike generator at the FTMS,
calibration, or interoperability layers. None uses the same energy path found in
this project: human power -> electrical generation -> battery/dump load, with
pedaling resistance controlled by the amount of generated energy accepted.

This is a bounded comparison, not proof that no similar project exists anywhere.
Public-facing wording should therefore use "among the projects reviewed" or "I
have not found" rather than claiming absolute uniqueness.

---

## Comparison at a glance

| Project | What it starts from | Power/cadence source | How resistance changes | Main overlap | Main difference |
|---|---|---|---|---|---|
| [Arduino BLE Indoor Bike Fitness Machine](https://github.com/kswiorek/ble-ftms) | Conventional indoor bike | Separate crank ESP32 measures power and cadence | Second ESP32 mechanically turns the resistance screw | FTMS implementation, gradient/resistance mapping, DIY construction | Two controllers and a mechanical brake; no energy generation/storage path |
| [SmartSpin2k](https://github.com/doudar/SmartSpin2k) | Spin bike with resistance knob | External/native power and cadence sensors, or learned estimates | ESP32 drives a stepper on the existing resistance knob | Mature FTMS modes, feedback ERG, homing, calibration, safety limits | Automates an existing brake; it does not turn rider power into stored electricity |
| [Gymnasticon](https://github.com/ptx2/gymnasticon) | Obsolete/proprietary connected bike | Reads the bike's existing proprietary data | Generally does not create or automate physical resistance | Protocol translation, reusable device adapters, BLE/ANT+ interoperability | Raspberry Pi gateway rather than a trainer/brake design |
| **Bike Generator** | Recovered stationary bike + scooter motor | Measures 24V-bus electrical power; speed/cadence currently simulated | ESP32 changes the buck converter's CC setting with a digipot | FTMS, DIY hardware, open interfaces | The generator is both energy source and electromagnetic brake; energy charges a battery and dump loads |

---

## What this project already does

This is not an early trainer mock-up that still needs a resistance mechanism.
The difficult physical integration already works:

```text
rider -> transmission -> scooter motor/generator -> rectifier -> CC/CV buck
      -> 24V bus -> BLUETTI battery + permanent halogen dump loads
                                      ^
                                      |
                  ESP32 -> SPI digipot -> CC setpoint
```

The firmware also already forms a coherent end-to-end system:

| Layer | Current implementation | What that means |
|---|---|---|
| Electrical sensing | `sensors.cpp` averages the ACS712 and voltage-divider ADC readings and calculates `V_bus * I_bus` | The transmitted watts are real electrical output measurements, not invented values |
| Electrical actuation | `resistance.cpp` writes the CC-network digipot: DFR0520/MCP42100 on the breadboard, MCP4151-104 on PCB V1 | Resistance is already controllable electronically, with no motorised friction knob |
| Manual control | A 0-100 command and the EnOcean buttons map across the safe digipot range | The bike remains usable without a training application |
| ERG command | FTMS target watts are converted to a wiper setting using the measured `30 -> 120W` calibration, plus a small 5W margin | It provides useful target-dependent resistance today, although it is feed-forward rather than regulated ERG |
| Simulation command | FTMS grade maps to `80W + 14W/%`, clamped to 0-200W | Zwift can already make climbs harder and descents easier |
| Telemetry | Bus watts plus modelled speed and cadence are sent as FTMS Indoor Bike Data | Applications receive a complete usable packet; only watts are directly measured |
| Compatibility | Control has been exercised with Zwift and TrainerDay | Interoperability is demonstrated, not merely theoretical |
| Safety boundary | Every wiper write is clamped to `POT_SAFE_MAX`, currently derived from the 200W energy-sink budget | A software command cannot directly request the full 0-255 digipot range |

This is already most of the architecture of a smart trainer. The open projects
are useful mainly for making its calibration, feedback, protocol handling and
diagnostics more mature. They do **not** supply the central innovation of this
project: using useful electrical generation as the controllable brake.

### Where the present implementation is deliberately simple

Understanding these boundaries makes the improvement list more precise:

- ERG uses `target watts -> wiper`; measured watts are reported but are not fed
  back into resistance control.
- The single calibration point assumes the same wiper/power relationship at all
  generator speeds and load states.
- Simulation resistance uses only grade. Wind speed, rolling-resistance and
  wind-resistance values are decoded and logged, but not applied to the load.
- Speed is calculated from bus watts and a road model; cadence is a smoothed
  heuristic derived from power. Neither is a shaft or crank measurement.
- `POT_SAFE_MAX` is an actuator clamp, not an independent over-current,
  over-voltage or over-temperature shutdown.
- The FTMS server supports the commands needed for the working modes, but does
  not yet implement a strict control-owner/session state machine. Reset,
  start/resume and stop/pause are acknowledged without changing the physical
  operating state.

Those are refinement opportunities, not evidence that the current concept is
missing. In particular, a mechanical stepper system from another project would
be a regression here: the generator and converter already provide fast, quiet,
wear-free electrical actuation while preserving the harvested energy.

---

## 1. Arduino BLE Indoor Bike Fitness Machine

This is the closest compact reference for the basic FTMS concept. Its README
describes two ESP32 boards: one measures crank power/cadence, while the other
emulates the trainer, forwards data, receives simulation parameters, and moves
the bike's resistance screw. It also supports an SD-card resistance program.

Its most relevant lesson is editorial as well as technical: the author found a
nominally realistic physics conversion difficult to make feel realistic and
added a graphical configurator for a user-defined gradient-to-resistance curve.

### Ideas worth taking

- **Real cadence sensing:** its separate crank sensor confirms that cadence is a
  useful independent input. The local project should use a Hall sensor or other
  direct RPM input, not copy its two-ESP32 layout.
- **A configurable grade curve:** expose the existing
  `FLAT_POWER_TARGET + grade * POWER_PER_GRADE_PERCENT` mapping as a small table
  or curve. This builds directly on working simulation mode and lets the rider
  tune feel where exact road physics cannot reproduce low-speed generator
  braking.
- **A repeatable profile mode:** its SD-card workouts suggest a useful bench-test
  facility. Replaying targets such as 30/60/90/120W would make calibration and
  regression testing much easier, even if profiles are sent over serial rather
  than stored on SD.
- **Separation of concerns:** this is already present locally in
  `ble_ftms.cpp`, `control_modes.cpp`, `resistance.cpp`, `sensors.cpp` and
  `physics.cpp`; retain that separation as feedback control is added.

### Ideas not needed yet

- Two ESP32 boards add communication and maintenance complexity. The current
  ESP32-C3 can remain the single controller unless radio concurrency, pin count,
  or timing measurements demonstrate a need to split the system.
- Mechanically turning a resistance screw would duplicate a function already
  achieved electrically by the digipot.

### Best source locations to study

- [`code/indoorBike`](https://github.com/kswiorek/ble-ftms/tree/master/code/indoorBike)
  for FTMS control and resistance behaviour;
- [`code/configurator`](https://github.com/kswiorek/ble-ftms/tree/master/code/configurator)
  for the user-defined grade curve;
- [`code/powerCrank`](https://github.com/kswiorek/ble-ftms/tree/master/code/powerCrank)
  for direct cadence/power acquisition.

No explicit software license was visible in this repository when reviewed.
That makes it a reference for behaviour and architecture, **not a source from
which code should be copied**, unless the author supplies permission or a
license.

---

## 2. SmartSpin2k

SmartSpin2k is the strongest reference for control quality and productisation.
It uses an ESP32 and stepper motor to automate an existing spin-bike resistance
knob. Its current firmware implements FTMS control modes, sensor connections,
homing, step limits, persistent settings, logging, and a companion interface.

Its ERG controller is particularly relevant. SmartSpin2k learns a power table
indexed by cadence, measured watts, and stepper position. On a large target
change it uses the table for a feed-forward jump, waits for the mechanics and
power reading to settle, then applies bounded feedback correction. It also
handles minimum cadence and physical travel limits.

### Ideas worth taking first

1. **A two-dimensional calibration table**

   Replace the single `wiper -> watts` factor with:

   ```text
   (measured RPM, wiper) -> bus watts
   ```

   Generator loading depends on speed, so a one-dimensional calibration cannot
   represent the system over the full cadence range. In this project, `wiper`
   replaces stepper position and real generator RPM may be a better independent
   variable than crank cadence.

2. **Feed-forward plus feedback ERG**

   Use the calibration table to choose an initial wiper, then correct slowly
   from measured bus-power error. This is more stable than asking a fast PID to
   discover the whole setting from scratch. It also preserves the good part of
   the current implementation: `Resistance_SetFromPower()` already supplies a
   simple, immediate feed-forward estimate.

3. **Explicit limits and safe states**

   Treat minimum/maximum wiper, maximum current/power, minimum cadence, sensor
   validity, disconnect, and thermal limits as controller states rather than
   scattered clamps.

   The existing `POT_SAFE_MAX` remains a valuable final clamp. The improvement
   is to add a limiting reason and measured protections around it, not replace
   it.

4. **Persistent, inspectable calibration**

   Store the calibration version and samples, and allow export/import. Record
   the lamp configuration and load/battery conditions used to create it.

5. **Settling time and logging**

   After a resistance change, wait for electrical and mechanical transients
   before learning a calibration point. Log targets, measurements, wiper, and
   limiting reason together.

6. **FTMS procedure state**

   Track which client owns control, validate command lengths/ranges, make Reset
   restore a defined state, and make Stop/Pause unload the generator safely.
   This is protocol hardening around the already working local control point.

### What must be adapted rather than copied

SmartSpin2k controls a mechanical knob with position and travel endpoints. This
project controls an electrical converter and instead needs voltage, current,
temperature, speed, and safe-power envelopes. Stepper homing logic is therefore
not directly applicable, but its broader concept of known actuator limits is.

Its control loop also assumes that adding mechanical resistance has a broadly
repeatable relationship with cadence and power. Here the battery input,
converter operating region and dump-load temperature can all change that
relationship. A local calibration table should therefore record load state and
reject samples collected during voltage/current transitions rather than copying
the SmartSpin2k table blindly.

### Best source locations to study

- [`src/ERG_Mode.cpp`](https://github.com/doudar/SmartSpin2k/blob/develop/src/ERG_Mode.cpp)
  for the feed-forward/setpoint and bounded feedback sequence;
- [`src/Power_Table.cpp`](https://github.com/doudar/SmartSpin2k/blob/develop/src/Power_Table.cpp)
  and
  [`src/PowerTable_Helpers.cpp`](https://github.com/doudar/SmartSpin2k/blob/develop/src/PowerTable_Helpers.cpp)
  for sample validation, interpolation and monotonic correction;
- [`include/settings.h`](https://github.com/doudar/SmartSpin2k/blob/develop/include/settings.h)
  for control delays, table dimensions and safety/tuning constants;
- [`src/BLE_Fitness_Machine_Service.cpp`](https://github.com/doudar/SmartSpin2k/blob/develop/src/BLE_Fitness_Machine_Service.cpp)
  for a more mature FTMS implementation;
- [`test`](https://github.com/doudar/SmartSpin2k/tree/develop/test) for examples
  of native tests around firmware logic.

SmartSpin2k software is GPL-2.0. Its algorithms and architecture are excellent
study material, but directly copying GPL code would require compatible
licensing of the resulting combined firmware. For this MIT repository, the
safe default is an independent implementation based on the documented control
ideas, unless the project is intentionally relicensed.

---

## 3. Gymnasticon

Gymnasticon reads proprietary bike protocols and re-broadcasts standard BLE/ANT+
power and cadence. Its goal is to free existing bikes from discontinued or
closed software. The Raspberry Pi may act as both Bluetooth client and server,
with distinct adapters when simultaneous roles require it.

Gymnasticon is not close to the generator or resistance principle. It is close
to the project's ambition of keeping physical equipment useful through standard
interfaces.

### Ideas worth taking

- Define a clean sensor/actuator adapter interface so firmware, Web Bluetooth,
  Unity, and future hardware revisions share the same semantic data. The local
  firmware already has good module boundaries; the missing piece is a stable
  data contract that distinguishes measured, derived, target and limiting-state
  values.
- Keep scale and offset calibration explicit.
- Document which devices/apps are actually tested separately from those merely
  expected to work through a standard.
- Make adding a new data source a small, documented extension rather than a
  rewrite of the FTMS server.

### Ideas not needed yet

- A Raspberry Pi gateway is unnecessary for the current ESP32 implementation.
- ANT+ and proprietary-bike adapters should wait for a demonstrated use case.

### Best source locations to study

- [`src/bikes`](https://github.com/ptx2/gymnasticon/tree/main/src/bikes) for
  the replaceable bike-client adapter pattern;
- [`src/app`](https://github.com/ptx2/gymnasticon/tree/main/src/app) for
  configuration and composition;
- [`src`](https://github.com/ptx2/gymnasticon/tree/main/src) for the boundary
  between proprietary input, normalized bike data and standard output.

Gymnasticon is MIT-licensed, so its code is the least problematic to reuse with
the required copyright/license notice. Most of it is Node.js/Raspberry Pi code,
however, so its interfaces are more transferable than its implementation on an
ESP32.

---

## Recommended adoption order

The aim is to strengthen the existing bike incrementally. None of these stages
requires replacing the generator, converter, digipot, FTMS service or modular
firmware structure.

### Stage 0: document and test what already works

1. Add structured serial output containing timestamp, mode, FTMS target, grade,
   wiper, `V_bus`, `I_bus`, bus watts and clamp/limit reason.
2. Add host-side tests for the pure mappings: level-to-wiper, watts-to-wiper,
   grade-to-watts, clamping and FTMS byte parsing.
3. Create a repeatable 30/60/90/120W steady-state test procedure.

This gives the current design a baseline before its behaviour changes.

### Stage 1: measurement before closed-loop control

1. Add real crank cadence or generator RPM.
2. Log rectifier input voltage as well as 24V output voltage/current.
3. Characterise several steady RPM/wiper points.
4. Identify CC, CV, drop-out, and load-transition regions.

The first three measurements should answer whether the observed resistance
"knee" is normal constant-power operation, converter drop-out, BLUETTI input
control, or a combination. See the
[pedaling-resistance physics note](pedaling-resistance-physics.md) for the test.

### Stage 2: closed-loop bus-power ERG

1. Build an RPM/wiper/power calibration surface.
2. Keep the current linear mapping as a fallback feed-forward path.
3. Add slow, bounded correction from measured bus-power error.
4. Add minimum-RPM, sensor-validity, over-voltage, over-current and temperature
   states, plus ramp limits and anti-windup.
5. Offer a tunable grade-to-resistance curve before attempting exact road-load
   simulation.

This creates genuine regulation of **delivered electrical power**. It still
does not claim crank watts, because drivetrain/generator/converter losses have
not been measured.

### Stage 3: FTMS and product maturity

1. Persistent/exportable calibration and configuration.
2. Structured logs and automated test rides.
3. Complete FTMS session/ownership, reset and pause behaviour.
4. Real temperature monitoring and active dump-load control.
5. A hardware abstraction layer for alternate sensors, generators, batteries,
   and loads.

### Stage 4: optional ride-feel hardware

Only after measurements show that software cannot provide acceptable low-speed
torque should the project consider an additional eddy-current brake or flywheel.
That hardware would complement the generator below its useful voltage range;
it would not replace electrical energy recovery.

---

## Practical source-use summary

| Need | Best reference | Reuse approach |
|---|---|---|
| Understand FTMS packets and a simple grade curve | ble-ftms `indoorBike` and `configurator` | Study and independently implement; no explicit license found |
| Add real cadence acquisition | ble-ftms `powerCrank` | Use the sensing concept; a local Hall interrupt will be much smaller |
| Improve ERG response | SmartSpin2k `ERG_Mode.cpp` | Reimplement feed-forward + bounded correction for a digipot/electrical plant |
| Learn an RPM/wiper/power surface | SmartSpin2k power-table files | Adapt the sampling and validation concepts; do not copy GPL code into MIT firmware |
| Harden FTMS behaviour | SmartSpin2k FTMS service | Compare procedure handling and tests; independently implement |
| Add replaceable data sources | Gymnasticon `src/bikes` | Its MIT adapter pattern/code may be reused with attribution, but translate it to embedded C++ |
| Add ANT+/legacy-bike bridges | Gymnasticon | Defer unless a real integration needs them |

---

## Conclusion

The reviewed projects validate the FTMS and open-interoperability parts of the
approach. SmartSpin2k provides the most useful control-system precedent, while
ble-ftms supports configurable feel over overly confident simulated physics.
Gymnasticon validates the value of a clean translation layer.

The bike generator remains materially different in its physical principle: its
controllable load is also an energy destination. The next improvement should not
copy another mechanical trainer; it should apply their calibration and feedback
discipline to this project's electrical energy path.

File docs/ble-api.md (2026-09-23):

# BLE API Reference — ESP32 Bike Trainer

How to connect to the bike trainer over Bluetooth and exchange data with it.
Written for hackathon participants building apps, games, or simulations.

The bike implements the **Bluetooth Fitness Machine Service (FTMS)**, a standard
protocol (Bluetooth SIG specification). Any BLE library that can connect to GATT
services will work — Web Bluetooth, bleak (Python), Unity BLE plugins, etc.

---

## Quick Facts

| Property | Value |
|---|---|
| **Device name** | `ESP32 Bike Trainer` |
| **BLE role** | Peripheral (server) |
| **Protocol** | FTMS — Bluetooth Fitness Machine Service |
| **Service UUID** | `1826` (0x1826) |
| **Update rate** | Power / speed / cadence pushed every **500 ms** |

---

## Connecting

1. Scan for BLE peripherals advertising the name `ESP32 Bike Trainer`
   or service UUID `0x1826`.
2. Connect and discover the Fitness Machine Service (`0x1826`).
3. Subscribe (enable notifications) on the **Indoor Bike Data** characteristic
   (`0x2AD2`) — without this the bike will not push updates.

---

## Characteristics

| Name | UUID | Properties | Description |
|---|---|---|---|
| Fitness Machine Feature | `0x2ACC` | Read | Supported features bitmap |
| **Indoor Bike Data** | `0x2AD2` | Notify | Live speed, cadence, power |
| Training Status | `0x2AD3` | Notify | Training state |
| Supported Resistance Range | `0x2AD6` | Read | Min/max/step for resistance |
| Supported Power Range | `0x2AD8` | Read | Min/max/step for power |
| **Fitness Machine Control Point** | `0x2AD9` | Write + Indicate | Send commands |
| Fitness Machine Status | `0x2ADA` | Notify | Mode change notifications |

The two you will use most are **Indoor Bike Data** (reading) and
**Fitness Machine Control Point** (writing).

---

## Indoor Bike Data — Reading Live Values

**UUID:** `0x2AD2`
**Direction:** Bike → your app (notification, every 500 ms)
**Format:** little-endian binary

### Byte layout

| Bytes | Field | Type | Unit | Notes |
|---|---|---|---|---|
| 0–1 | Flags | uint16 LE | — | `0x0024` = cadence + power present |
| 2–3 | Instantaneous Speed | uint16 LE | km/h × 100 | Divide by 100 for km/h |
| 4–5 | Instantaneous Cadence | uint16 LE | RPM × 2 | Divide by 2 for RPM |
| 6–7 | Instantaneous Power | int16 LE | Watts | Signed; always ≥ 0 here |

### Parsing examples

**Python (bleak):**
```python
import struct

def parse_indoor_bike_data(data: bytes) -> dict:
    flags, speed_raw, cadence_raw, power_raw = struct.unpack_from('<HHHh', data)
    return {
        "speed_kmh":   speed_raw / 100.0,
        "cadence_rpm": cadence_raw / 2.0,
        "power_w":     power_raw,
    }
```

**JavaScript (Web Bluetooth):**
```javascript
function parseIndoorBikeData(dataView) {
  return {
    speedKmh:   dataView.getUint16(2, true) / 100,
    cadenceRpm: dataView.getUint16(4, true) / 2,
    powerW:     dataView.getInt16(6, true),
  };
}
```

**C# / Unity:**
```csharp
// data is byte[]
ushort speed = BitConverter.ToUInt16(data, 2);
ushort cad   = BitConverter.ToUInt16(data, 4);
short  power = BitConverter.ToInt16(data, 6);

float speedKmh   = speed / 100f;
float cadenceRpm = cad / 2f;
int   powerWatts = power;
```

**GDScript / Godot:**
```gdscript
func parse_bike_data(data: PackedByteArray) -> Dictionary:
    return {
        "speed_kmh":   data.decode_u16(2) / 100.0,
        "cadence_rpm": data.decode_u16(4) / 2.0,
        "power_w":     data.decode_s16(6),
    }
```

---

## Fitness Machine Control Point — Sending Commands

**UUID:** `0x2AD9`
**Direction:** your app → Bike (write with response)
**Response:** 3-byte indication; byte[2] == 0x01 means success

### Protocol

1. Write `[0x00]` (Request Control) first — always required
2. Write your command
3. Wait for the indication response before sending the next command

### Available commands

#### Request Control (always first)
```
[0x00]
```

#### Set Resistance Level — Manual mode
```
[0x04, level]
```
`level`: uint8, 0 = minimal resistance, 100 = maximum

#### Set Target Power — ERG mode
```
[0x05, watts_low, watts_high]
```
`watts`: int16 little-endian. The current firmware maps this target to a calibrated
digipot position. This is open-loop control: it does not yet correct the setting
from the difference between requested and measured power.

#### Set Indoor Bike Simulation — gradient mode
```
[0x11, windSpeed_low, windSpeed_high, grade_low, grade_high, crr, cw]
```

| Field | Type | Unit | Typical value |
|---|---|---|---|
| windSpeed | int16 LE | m/s × 1000 | `0x0000` |
| grade | int16 LE | % × 100 | `0x0000` flat, `0x01F4` = +5%, `0xFF9C` = -1% |
| crr | uint8 | × 10000 | `40` |
| cw | uint8 | kg/m × 100 | `51` |

Only `grade` has an effect — wind, crr and cw are accepted but ignored.

#### Reset
```
[0x01]
```

---

## Full Code Examples

**Python — subscribe + ERG mode:**
```python
import asyncio, struct
from bleak import BleakClient, BleakScanner

BIKE_DATA = "00002ad2-0000-1000-8000-00805f9b34fb"
CTRL_PT   = "00002ad9-0000-1000-8000-00805f9b34fb"

def on_data(sender, data):
    _, speed, cad, pwr = struct.unpack_from('<HHHh', data)
    print(f"Power={pwr}W  Speed={speed/100:.1f}km/h  Cadence={cad/2:.0f}rpm")

async def main():
    device = await BleakScanner.find_device_by_name("ESP32 Bike Trainer")
    async with BleakClient(device) as client:
        await client.start_notify(BIKE_DATA, on_data)
        await client.write_gatt_char(CTRL_PT, bytes([0x00]), response=True)  # request control
        cmd = struct.pack('<Bh', 0x05, 150)  # ERG: 150W target
        await client.write_gatt_char(CTRL_PT, cmd, response=True)
        await asyncio.sleep(60)

asyncio.run(main())
```

**JavaScript — resistance slider:**
```javascript
let ctrlChar;

async function connect() {
  const device = await navigator.bluetooth.requestDevice({
    filters: [{ name: "ESP32 Bike Trainer" }],
    optionalServices: ["00001826-0000-1000-8000-00805f9b34fb"]
  });
  const server  = await device.gatt.connect();
  const service = await server.getPrimaryService("00001826-0000-1000-8000-00805f9b34fb");

  const dataChar = await service.getCharacteristic("00002ad2-0000-1000-8000-00805f9b34fb");
  await dataChar.startNotifications();
  dataChar.addEventListener("characteristicvaluechanged", e => {
    const dv = e.target.value;
    console.log("Power:", dv.getInt16(6, true), "W");
  });

  ctrlChar = await service.getCharacteristic("00002ad9-0000-1000-8000-00805f9b34fb");
  await ctrlChar.writeValueWithResponse(new Uint8Array([0x00]));
}

async function setResistance(level) {
  await ctrlChar.writeValueWithResponse(new Uint8Array([0x04, level]));
}

async function setTargetPower(watts) {
  const buf = new ArrayBuffer(3);
  new DataView(buf).setUint8(0, 0x05);
  new DataView(buf).setInt16(1, watts, true);
  await ctrlChar.writeValueWithResponse(new Uint8Array(buf));
}

async function setGrade(gradePercent) {
  const raw = Math.round(gradePercent * 100);
  const buf = new ArrayBuffer(7);
  const v = new DataView(buf);
  v.setUint8(0, 0x11);
  v.setInt16(1, 0, true);    // wind = 0
  v.setInt16(3, raw, true);  // grade
  v.setUint8(5, 40);
  v.setUint8(6, 51);
  await ctrlChar.writeValueWithResponse(new Uint8Array(buf));
}
```

---

## Control Modes Summary

| Mode | OpCode | What the bike does | Best for |
|---|---|---|---|
| **Manual** | `0x04` | Fixed resistance 0–100 | Free riding, warmup |
| **ERG** | `0x05` | Holds target wattage | Power-based games, intervals |
| **Simulation** | `0x11` | Resistance from road slope | Terrain / racing games |

---

## Value Ranges

| Parameter | Min | Max | Resolution |
|---|-----|-----|---|
| Power (received) | 0 W | ~200 W | 1 W |
| Speed (received) | 0 km/h | ~35 km/h | 0.01 km/h |
| Cadence (received) | 0 RPM | 120 RPM | 0.5 RPM |
| Resistance (sent) | 0 | 100 | 1 |
| Target power (sent) | 0 W | 200 W | 1 W |
| Grade (sent) | -10% | +12.5% | 0.01% |

---

## Tips for Game Developers

- **Poll rate is 500 ms** — smooth your display with interpolation, not raw values.
- **Speed and cadence are simulated** — derived from power by the firmware, not
  measured by a sensor. Treat as reasonable approximations.
- **ERG mode has latency** — resistance change takes 1–3 pedal strokes to settle.
  Do not send commands faster than once per second.
- **Power fluctuates** — expect ±10 W from pedaling rhythm. Use a rolling average
  of 3–5 samples for display and game logic.
- **No pairing required** — the device is open; no PIN or bonding needed.
- **Give the ESP32 ~2 seconds after power-on** before connecting.

---

*See also: [Build Tutorial](build-tutorial.md) · [Firmware Architecture](firmware.md) · [Component References](components/README.md)*

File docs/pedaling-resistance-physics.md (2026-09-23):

# Why the Generator Resists Pedaling

This note separates what is physically happening in the bike from what the
firmware estimates. It also explains the observed behaviour where a 30W, 60W,
or 90W setting becomes progressively harder to reach, but seems to soften after
a particular pedaling speed.

The short version is:

> A generator only brakes while electrical current is being taken from it.
> The converter controls how much current the loads may receive. Once that
> limit is reached, the system behaves approximately like a constant-power
> load: pedaling faster no longer increases accepted power, so opposing torque
> decreases with speed.

That is the leading explanation for the observed "critical point". It should be
confirmed with the measurements described below because converter drop-out,
the BLUETTI input controller, or a protection cycle could make the transition
sharper.

---

## 1. Energy path

```text
legs -> cranks -> transmission -> scooter motor -> three-phase AC
     -> rectifier -> unregulated DC -> CC/CV buck converter -> 24V bus
     -> BLUETTI + permanently connected halogen loads
```

Energy is conserved across this chain, apart from losses:

```text
P_rider = P_bus + P_mechanical_losses + P_motor_losses
                  + P_rectifier_losses + P_converter_losses
```

The present ACS712 and voltage divider measure the **24V bus output** after the
buck converter:

```text
P_bus = V_bus * I_bus
```

This is real delivered electrical power. It is not exactly crank power. Crank
power is higher because bearings, the transmission, motor windings, rectifier,
and converter all dissipate energy.

If total efficiency is `eta_total`:

```text
P_rider ~= P_bus / eta_total
```

Efficiency has not yet been measured, so the firmware and portfolio should call
the reported value **bus electrical power**, not calibrated human power.

---

## 2. Why drawing electricity creates braking torque

A permanent-magnet motor used backwards behaves as a generator.

Its generated voltage grows approximately with shaft speed:

```text
E ~= k_e * omega_motor
```

When the circuit draws current, the magnetic interaction produces an opposing
torque:

```text
tau_motor ~= k_t * I_motor
```

`k_e` and `k_t` describe the same motor construction in different units. With
the electrical circuit open, voltage may be present but current is almost zero,
so electromagnetic braking is also almost zero. Only bearing friction, belt
losses, cogging, and air drag remain.

When the converter and loads draw more current, generator counter-torque rises.
That counter-torque is transmitted back through the belt/gearing to the cranks,
which is why increasing the electrical load makes pedaling harder.

The DC bus current measured by the ACS712 is not identical to motor phase
current, so it cannot be converted directly into motor torque without also
knowing converter efficiency, rectified input voltage, and the motor constants.

---

## 3. Power, torque, and cadence are different quantities

Mechanical power is:

```text
P = tau * omega
```

At the cranks, using cadence `n` in RPM:

```text
omega_crank = 2*pi*n/60
tau_crank = 60*P_rider/(2*pi*n)
```

For the same power, a slower cadence requires more torque per pedal stroke. The
following values are ideal lower bounds using electrical output power directly;
real crank torque is higher because efficiency is below 100%.

| Bus power | 60 RPM | 90 RPM | 120 RPM |
|---:|---:|---:|---:|
| 30W | 4.8 N·m | 3.2 N·m | 2.4 N·m |
| 60W | 9.5 N·m | 6.4 N·m | 4.8 N·m |
| 90W | 14.3 N·m | 9.5 N·m | 7.2 N·m |

If total efficiency were 70%, for example, all of those crank-torque values
would be about `1/0.70 = 1.43` times higher. This is only an illustration; the
actual efficiency must be measured.

---

## 4. What the CC/CV converter controls

The converter has two feedback limits:

- **CV** sets the maximum output voltage, nominally 24V.
- **CC** sets the maximum output current.

The digital potentiometer modifies the converter's CC setting. At a stable 24V
bus, an output-current ceiling is also approximately a power ceiling:

```text
P_bus,max ~= 24V * I_limit
```

Examples at a true 24V output would be:

| Nominal power ceiling | Approximate bus-current ceiling |
|---:|---:|
| 30W | 1.25A |
| 60W | 2.50A |
| 90W | 3.75A |
| 120W | 5.00A |

The current firmware does not command those currents directly. It assumes a
linear, single-point calibration between digipot position and measured power:

```text
wiper = target_watts * POT_CAL_VALUE / POT_CAL_POWER
```

Consequently, "30W mode" currently means "the wiper position predicted to give
about 30W under calibration conditions." It is not a closed-loop 30W regulator.
The result can change with speed, battery charge state, lamp temperature, and
converter operating region.

---

## 5. The operating regions felt by the rider

### Region A — below generator/converter cut-in

At low speed, generated voltage may be too low for the buck converter to hold a
24V output. A buck converter can only step voltage down; it cannot boost a lower
input to 24V. The electrical load is weak or disconnected and pedaling feels
light.

The precise cut-in speed depends on motor constant, transmission ratio,
rectifier voltage drop, converter minimum input/headroom, and BLUETTI behaviour.

### Region B — loaded, below the current ceiling

Once rectified generator voltage is high enough, current flows to the loads.
With resistive lamps, current and power rise with voltage; generator braking
therefore rises strongly with speed. This is the part that feels progressively
harder.

### Region C — CC ceiling reached: approximately constant power

When bus current reaches the configured CC ceiling while the output remains near
24V, accepted output power stops increasing:

```text
P_bus ~= constant
```

Ignoring losses, converter input current then behaves approximately as:

```text
I_in ~= P_bus / (eta_converter * V_in)
```

Generator voltage increases with speed. Therefore, above the power ceiling,
input current and generator counter-torque decrease approximately as speed
increases:

```text
tau_generator proportional to I_in proportional to 1 / speed
```

The rider first climbs toward a peak load, reaches the ceiling, and then finds
that pedaling faster does not demand proportionally more effort. Subjectively it
can feel like the resistance "lets go" or disappears. A higher 60W or 90W
ceiling moves this transition to a higher effort, matching the observation.

This is not how a purely frictional brake behaves. It is a natural consequence
of limiting **power** rather than maintaining **torque**.

### Region D — another device changes state

The transition can be more abrupt than the constant-power model predicts if:

- the buck enters/exits voltage regulation or drop-out;
- the BLUETTI changes its accepted input current or MPPT-like operating point;
- its input temporarily disconnects;
- the converter reaches thermal or over-current protection;
- hot halogen resistance changes the load sharing;
- the digipot/CC network is nonlinear near that setting.

These possibilities cannot be distinguished using only output watts.

---

## 6. How to identify the real transition

Measure at least these five values at the same time:

1. crank or generator speed (RPM);
2. rectified voltage **before** the buck (`V_in`);
3. current **before** the buck (`I_in`), if a suitable sensor is available;
4. 24V bus voltage after the buck (`V_bus`);
5. 24V bus current after the buck (`I_bus`).

Also record wiper position, lamp configuration, BLUETTI state of charge, and
whether the BLUETTI is connected.

For each wiper setting, hold several steady speeds from easy pedaling through the
softening point. Do not test by accelerating continuously: steady points make
the converter's operating regions visible.

Suggested table:

| Wiper | RPM | V_in | I_in | V_bus | I_bus | P_in | P_bus | Felt behaviour |
|---:|---:|---:|---:|---:|---:|---:|---:|---|
| | | | | | | `V_in*I_in` | `V_bus*I_bus` | |

Interpretation:

| Observation at the softening point | Likely explanation |
|---|---|
| `I_bus` plateaus and `V_bus` stays near 24V | Normal CC / constant-power ceiling |
| `V_bus` falls while `I_bus` is limited | Source voltage/drop-out or converter current limiting |
| `V_in` rises while `I_in` falls and `P_bus` stays flat | Constant-power behaviour confirmed |
| Voltage/current repeatedly jump or pulse | BLUETTI or converter protection/control cycling |
| Behaviour changes greatly without the BLUETTI | BLUETTI input control is part of the knee |
| Behaviour changes as lamps warm | Nonlinear lamp resistance/load sharing |

Run a comparison with the BLUETTI disconnected and a known, safely rated dump
load only. Keep the 10A fuse, remain below component ratings, and do not perform
this test without a guaranteed load for generated energy.

---

## 7. Consequences for control software

### Current firmware

- `Resistance_SetFromPower()` is feed-forward/open-loop.
- One calibration point assumes wiper-to-power is linear.
- Electrical power is measured, but it is not used to correct the wiper.
- Cadence and speed are simulated, so the controller cannot know actual shaft
  speed or actual crank torque.

### Recommended next control step

Build a two-dimensional calibration map:

```text
(real RPM, wiper position) -> measured bus power
```

Then add a slow, bounded feedback correction around that feed-forward map:

```text
error = target_bus_power - measured_bus_power
wiper = feed_forward(RPM, target) + bounded_feedback(error)
```

Required safeguards:

- real cadence or generator-speed sensor;
- minimum cadence before resistance is increased;
- wiper, power, voltage, current, and temperature limits;
- ramp-rate limits so resistance cannot jump;
- anti-windup when the requested power is physically unreachable;
- immediate safe minimum on sensor failure or disconnect.

This would make ERG genuinely closed-loop for **bus electrical power**. Calling
it crank-power ERG would additionally require a crank power meter or a measured
efficiency model.

### Simulation mode is a different problem

A road gradient is not a fixed wattage. Required road power depends on speed:

```text
P_road = (Crr*m*g + m*g*grade + 0.5*rho*CdA*v^2) * v
```

To reproduce that behaviour, the system needs real speed and a feedback loop.
A simpler, honest alternative is a user-tuned `grade -> resistance` curve. This
may feel better than claiming exact road physics before sufficient sensing and
low-speed braking authority exist.

---

## 8. Claims that are safe today

- Pedaling drives a motor used as a generator.
- Drawing more electrical current produces more opposing generator torque.
- The CC setting controls the maximum electrical load and therefore the felt
  resistance range.
- Bus voltage, current, and electrical output power are measured in real time.
- FTMS commands select calibrated resistance settings.

Claims to qualify:

- "30W resistance" means an approximate calibrated bus-output target.
- ERG is currently open-loop, not a guaranteed held power.
- Speed and cadence are simulated, not sensed.
- Bus electrical power is not identical to human mechanical power.

---

## References

- [maxon: Motor constants](https://support.maxongroup.com/hc/en-us/articles/360005873794-Motor-constants) — torque/current and generated voltage/speed relationships.
- [Texas Instruments: Constant-current/constant-voltage buck converter](https://www.ti.com/lit/an/snva829/snva829.pdf) — operation of CC and CV feedback loops.
- [Texas Instruments: DC/DC converter current limits](https://www.ti.com/lit/ta/ssztax7/ssztax7.pdf) — approximate input/output power relationship in switching converters.

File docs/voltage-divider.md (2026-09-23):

# Voltage Divider — Bus Voltage Measurement

The ESP32-C3 ADC pins are **3.3V maximum**. The bus runs at **24V**. A resistive voltage divider scales the bus voltage down to a safe level for the ADC.

---

## Circuit

```
Bus (+24V) ──[R1 = 100kΩ]──┬──[R2 = 7.5kΩ]── GND
                            │
                          GPIO1 (ADC)
```

Two resistors in series across the bus. The ADC reads the voltage at the junction between them.

> **⚠️ Avoid GPIO2** on ESP32-C3 — it is a strapping pin with a hardware pull-up that software cannot override, which inflates ADC readings. Use GPIO1 or GPIO3 instead.

---

## How it works

The junction voltage follows the resistor ratio:

$$V_{GPIO} = V_{BUS} \times \frac{R2}{R1 + R2}$$

With R1 = 100kΩ and R2 = 7.5kΩ:

$$V_{GPIO} = V_{BUS} \times \frac{7.5}{107.5} = V_{BUS} \times 0.0698$$

| Bus voltage | GPIO1 voltage |
|---|---|
| 24V (nominal) | **1.67V** ✅ |
| 30V | 2.09V ✅ |
| 40V (BLUETTI max) | **2.79V** ✅ safe without zener |

The 7.5kΩ / 107.5kΩ ratio stays safely below 3.3V all the way to 40V —
the BLUETTI DC input ceiling — with no zener clamp needed.

---

## Why these values

**R1 = 100kΩ, R2 = 7.5kΩ** is a deliberate choice on two axes:

### 1. Ratio — sets the measurement range

The ratio R2/(R1+R2) must map V_BUS_MAX to ≤ 3.3V.

For headroom up to 40V (BLUETTI DC input ceiling):

    R2 / (R1 + R2) ≤ 3.3 / 40 = 0.0825

100k + 7.5k gives 0.0698 — comfortably under the limit.
At 40V: V_GPIO = 2.79V ✅. No zener clamp required.

### 2. Total resistance — limits current draw

R1 + R2 = 107.5kΩ means the divider draws:

    I = 24V / 107.5kΩ ≈ 0.22 mA

Negligible on the bus. Using much lower values (e.g. 1kΩ + 120Ω) would work
electrically but waste power continuously.

---

## Changing the resistors

Edit **only** `VDIV_R1_OHMS` and `VDIV_R2_OHMS` in `config.h`.
The scale factor and maximum measurable voltage are derived automatically:

```c
#define VDIV_R1_OHMS    100000.0f
#define VDIV_R2_OHMS     7500.0f

// Derived — do not edit:
#define VDIV_RATIO      (VDIV_R2_OHMS / (VDIV_R1_OHMS + VDIV_R2_OHMS))
#define VDIV_SCALE      (1.0f / VDIV_RATIO)
```

---

## Calibration

Component tolerance (typically ±1–5%) will introduce a small offset. After wiring:

1. Measure actual bus voltage with a multimeter → note the value
2. Read serial output: `ADC volt: Vpin=1.67V → bus=24.0V`
3. If they differ, adjust `VDIV_OFFSET_V` in `config.h` by the difference

```c
// e.g. set to -0.4 if serial reads 24.4 but multimeter reads 24.0
#define VDIV_OFFSET_V   0.0f
```

---

## What happens at 40V?

At 40V (the BLUETTI DC input ceiling, reachable if the buck loses regulation),
with the **7.5kΩ divider**:

    V_GPIO = 40 × 7.5 / 107.5 = 2.79V  ✅  safe — no zener needed

This is exactly why 7.5kΩ was chosen over the more common 12kΩ. The 12kΩ variant
would produce 4.29V at 40V and destroy the ADC pin instantly.

---

## Safety

> The 7.5kΩ divider stays below 3.3V up to 40V — no additional protection needed
> for normal operation. If you ever swap to higher R2 values (e.g. 12kΩ), add a
> 3.3V zener from GPIO1 to GND.

Standard ¼W resistors are fine — the divider carries no meaningful current.

---

*See also: [Hardware Reference](hardware.md) · [config.h](../config.h)*

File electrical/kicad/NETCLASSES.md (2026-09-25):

# Netclasses PCB V1

Définition appliquée dans `bike-generator-controller.kicad_pro` le 26 septembre 2026.

## Contraintes globales

| Contrainte | Valeur |
|---|---:|
| Clearance minimale | 0,20 mm |
| Largeur minimale de piste | 0,20 mm |
| Via minimal | 0,60 / 0,30 mm |
| Distance trou à trou minimale | 0,25 mm |

## Classes

| Classe | Piste | Clearance | Via | Usage |
|---|---:|---:|---:|---|
| `Default` | 0,25 mm | 0,20 mm | 0,60 / 0,30 mm | Signaux numériques ordinaires |
| `POWER_20A` | 5,00 mm | 0,20 mm | 2,00 / 1,00 mm | Chemin positif principal |
| `HV_AUX` | 0,75 mm | 0,20 mm | 0,80 / 0,40 mm | Alimentation auxiliaire haute tension après `F2` |
| `GROUND_PLANE` | 1,00 mm | 0,20 mm | 0,80 / 0,40 mm | Masse, destinée principalement aux plans |
| `LV_POWER` | 0,75 mm | 0,20 mm | 0,80 / 0,40 mm | 3,3 V, 5 V et batterie LiPo |
| `MEASUREMENT` | 0,25 mm | 0,20 mm | 0,60 / 0,30 mm | Kelvin et mesure INA228 |
| `ANALOG_CTRL` | 0,25 mm | 0,20 mm | 0,60 / 0,30 mm | Boucles analogiques LM5164 et commande CC |
| `SW_NODE` | 1,00 mm | 0,20 mm | 0,80 / 0,40 mm | Nœud commuté du LM5164, à garder très court |
| `HV_FLOATING` | 0,25 mm | 0,20 mm | 0,60 / 0,30 mm | Bootstrap `BST`, référencé au nœud `SW` |

## Affectations particulières

- `POWER_20A` : `Net-(J4-Pin_1)`, `Net-(F1-Pad2)`, `/INA228_SENSE/VBUS_SENSE`.
- `HV_AUX` : `/AUX_SUPPLY/AUX_IN_PROTECTED`.
- `GROUND_PLANE` : `GND`.
- `LV_POWER` : `+3V3`, `/AUX_SUPPLY/AUX_5V`, `/MCU/BAT_CTRL`, `/MCU/BAT_RAW`, `/MCU/VIN_5V`.
- `MEASUREMENT` : les deux connexions Kelvin du shunt et les entrées différentielles INA228.
- `ANALOG_CTRL` : `CC_A/W/B`, `FB`, `RIPPLE`, `RON_SET`, `UVLO`.
- `SW_NODE` : `/AUX_SUPPLY/SW`.
- `HV_FLOATING` : `/AUX_SUPPLY/BST`.

## Limites et règles de routage

La largeur de 5 mm de `POWER_20A` est un minimum pratique pour le routage et les étranglements locaux, pas la validation thermique définitive du chemin 20 A. Le chemin principal devra utiliser des surfaces de cuivre aussi larges et courtes que possible, idéalement sur les deux faces. Un via isolé de 2,00 / 1,00 mm ne doit pas être considéré comme capable de transporter 20 A ; éviter tout changement de couche ou utiliser un réseau de vias dimensionné après choix du cuivre et du fabricant.

Le net `GND` mélange retours logique et puissance. Sa netclass ne peut donc pas garantir seule le retour 20 A : la liaison directe entre les connecteurs de puissance devra être réalisée et vérifiée comme un plan/chemin de cuivre dédié, tandis que les masses sensibles seront raccordées sans partager les chutes de tension du courant principal.

La clearance de 0,20 mm est volontairement compatible avec les land patterns validés du LM5164, de l'INA228 et du shunt. Des valeurs globales de 0,3 à 1,0 mm provoquent des violations internes aux empreintes. Hors des boîtiers, viser au routage au moins 0,60 mm autour des conducteurs pouvant atteindre le bus 80 V, et 1,00 mm lorsque l'espace le permet. Cette séparation renforcée devra être contrôlée pendant le routage et revue avant fabrication.

## Validation

- Les neuf classes ont été relues dans le projet ; aucune affectation n'est orpheline.
- Après routage du chemin principal, du filtre Kelvin INA228 et du bloc auxiliaire LM5164 : 86 erreurs, dont 72 connexions non routées et 14 erreurs connues sur les jumpers `JP1`/`JP2`. Aucune collision nouvelle n'a été introduite par ces pistes.
- Le LM5164 a désormais ses boucles `BST`/`SW`, son réseau d'injection `RIPPLE`, sa boucle `FB`, `UVLO`, `RON_SET`, `PGOOD`, les condensateurs d'entrée/sortie et le point de test 5 V routés. Les signaux sensibles qui changent de couche utilisent des vias 0,60 / 0,30 mm ; le condensateur traversant `C6` a été rapproché de l'entrée.
- La palette de largeurs prédéfinies de l'éditeur reste à ajouter lorsque le PCB sera fermé, car KiCad écraserait une modification externe effectuée pendant que le PCB est ouvert.

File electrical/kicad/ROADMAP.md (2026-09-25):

# Feuille de route KiCad — contrôleur du vélo générateur

Cette feuille de route ordonne le passage du prototype sur breadboard à une
première carte vérifiable. Elle ne transforme pas les hypothèses encore ouvertes
en choix de fabrication.

## Principes de travail

- Le buck CV/CC 400 W reste un module externe en V1.
- Le trajet de puissance de la carte est dimensionné provisoirement pour 400 W,
  20 A continus et 25 A transitoires.
- Les observations actuelles sont environ 36 V en charge et plus de 40 V lors
  de démarrages rapides. Elles ne remplacent pas la mesure de tension à vide,
  génératrice entraînée mais sortie déconnectée.
- La dérivation auxiliaire part de `BUS_PROTECTED`, après le fusible principal
  et le shunt, mais possède son propre fusible `F_AUX`.
- Le 5 V auxiliaire alimente `VIN_5V` du Beetle. La LiPo 1S protégée
  `801350`, 500 mAh, est raccordée à `BAT` par un interrupteur mécanique.
- `JP_GEN_5V` permet d'isoler physiquement le 5 V générateur pendant les essais
  USB. Il ne court-circuite aucune source.
- Aucun symbole, footprint ou modèle 3D personnalisé n'est créé sans recherche
  préalable et accord explicite.
- Aucun circuit de sécurité ne repose uniquement sur le firmware.
- Le firmware reste hors périmètre jusqu'à l'existence de la première carte
  physique ; les travaux courants portent uniquement sur le matériel et sa
  validation électrique.

## Ordre de réalisation

### 1. Valider le LM5164 et ses modèles KiCad — CAO et variante V1 validées

Objectif : disposer d'une correspondance prouvée entre le composant physique,
le symbole et le footprint avant de placer le régulateur.

- [x] archiver la fiche TI `SNVSAU4D` ;
- [x] relever le brochage `DDA0008B` et sa vue ;
- [x] vérifier la présence du symbole KiCad `Regulator_Switching:LM5164DDA` ;
- [x] comparer son brochage avec la fiche TI ;
- [x] comparer le footprint associé par défaut au land pattern TI révisé ;
- [x] examiner le modèle KiCad v6+ proposé par TI/Ultra Librarian : paquet
  rejeté pour incohérences de noms, vias et géométrie ;
- [x] retenir `LM5164DDAT` pour le prototypage (`LM5164DDAR` ne diffère que par
  le conditionnement en grande bobine) ;
- [x] confirmer le footprint standard KiCad basé sur `DDA0008B`, avec pads IPC
  plus longs et pâte segmentée ;
- [x] relire avec Konnect les 9 pins du symbole et les pads 1 à 9 du footprint
  standard retenu ; les huit vias thermiques portent bien le numéro 9 ;
- [x] placer, relire et rendre le symbole dans un projet jetable ;
- [x] placer, relire et rendre le footprint dans le PCB jetable ; contrôler le
  repère 1, les pads, le masque, la pâte et les huit vias thermiques ;
- [x] créer après accord la variante projet à six vias Ø0,60/0,30 mm, conserver
  le pad exposé, le masque et la pâte validés, puis refaire le DRC ;
- [x] affecter la variante locale à U4 :
  `BikeGenerator:SOIC-8-1EP_DDA_EP2.95x4.9mm_6Vias_D0.30mm`.

Critère de sortie CAO V1 : atteint. Le PCB jetable donne zéro erreur et zéro
violation de règle ; son seul avertissement est l'empreinte volontairement sans
schéma. Avant fabrication, confirmer l'anneau de 0,15 mm et le traitement des
vias sous pad avec le fabricant.

### 2. Construire le trajet de puissance dans `POWER_PATH` — squelette validé

- [x] placer un connecteur d'entrée redressée provisoire ;
- [x] placer le fusible principal provisoire ;
- [x] placer un shunt quatre bornes 2 mΩ provisoire avec sorties Kelvin
  distinctes ;
- [x] créer `BUS_PROTECTED` après le shunt ;
- [x] créer le départ court vers le buck CV/CC externe ;
- [x] raccorder `SHUNT_HI_K`, `SHUNT_LO_K` et `BUS_PROTECTED` aux entrées
  `SHUNT_HI_K`, `SHUNT_LO_K` et `VBUS_SENSE` de la feuille INA228 ;
- [x] créer le départ auxiliaire protégé par `F_AUX` ;
- [x] documenter une première présélection : Bourns
  `CSS4J-4026K-2L00F`, `0449001.MR` et Anderson PP15/45 ; le fusible principal
  est désormais spécifié ≤ 20 A / ≥ 125 V DC et reste source-spécifique ;
- [x] retenir `CSS4J-4026K-2L00F` et lui affecter l'empreinte KiCad native
  `Resistor_SMD:R_Shunt_Isabellenhuette_BVR4026`, dont le land pattern est
  identique au dessin Bourns ;
- [x] retenir pour `J4` et `J5` le bornier Phoenix Contact `1711725`, 24 A /
  400 V, avec son empreinte KiCad native MKDS-3 au pas de 5,08 mm ;
- [x] retenir l'Eaton Bussmann `ABC-V-20-R`, créer son empreinte axiale locale
  au pas choisi de 38,10 mm et l'affecter à `F1` ;
- [ ] dimensionner la protection contre inversion et transitoires après les
  mesures de la génératrice.

Le contrôle Konnect du 24 septembre 2026 donne zéro fil flottant, zéro pin non
connectée, zéro élément orphelin et zéro court-circuit de nets. Depuis l'ajout
de `AUX_SUPPLY`, `AUX_IN_PROTECTED` alimente bien le LM5164.

Critère de sortie du squelette : atteint. La sélection physique des composants
reste indispensable avant tout PCB commandable.

### 3. Concevoir le buck auxiliaire sur bus protégé jusqu'à 80 V vers 5 V

- [x] créer la feuille hiérarchique `AUX_SUPPLY` et la relier à
  `AUX_IN_PROTECTED` ;
- [x] placer le LM5164 validé avec la variante locale V1 dérivée de DDA0008B ;
- [x] effectuer un premier calcul sourcé de `RON`, `EN/UVLO`, retour 5 V,
  inductance, réseau d'ondulation et condensateurs pour 600 mA continus avec
  marge jusqu'à 1 A ;
- [x] traduire ce calcul en un premier schéma : UVLO, `RON`, pont de retour,
  bootstrap, inductance, condensateurs et réseau Type-3 ;
- [x] ajouter les points de test `AUX_IN`, `AUX_5V`, `AUX_PGOOD` et `GND` ;
- [x] relire les neuf nets de U4 et vérifier zéro orphelin, zéro court-circuit
  de nets et zéro chevauchement de symboles ;
- [ ] rejouer ce calcul dans le calculateur officiel TI/WEBENCH ;
- [x] sélectionner les références commandables des résistances, MLCC et de L1,
  avec des empreintes KiCad standard favorisant la soudure manuelle ;
- [x] choisir `C6` : Panasonic `EEU-FC2A100`, avec empreinte KiCad native ;
- [x] vérifier les courbes fabricant des MLCC : remplacer les deux 2,2 µF /
  100 V d'entrée insuffisants à 80 V par trois 10 µF / 100 V X7S ; conserver
  les deux 22 µF / 16 V de sortie ;
- [x] reporter cette correction dans `AUX_SUPPLY` : mettre `C4` et `C5` à
  `CL32Y106KCVZ4NE` / 10 µF et ajouter `C13` identique en parallèle, sans
  renuméroter les références existantes ;
- [ ] vérifier les pertes de L1 avec le profil de charge définitif et confirmer
  thermiquement les MLCC d'entrée sur prototype ;
- [x] retenir électriquement `0449001.MR` pour `F_AUX`, créer son land pattern
  Littelfuse exact et l'affecter à `F2` ; retirer `SMCJ48A` comme choix
  générique, incompatible avec 80 V continus ;
- [ ] choisir une TVS source-spécifique après mesure des transitoires ; aucun
  composant parallèle standard ne garantit à la fois veille à 80 V et clamp
  sous 85 V ;
- [x] raccorder `AUX_5V` au bloc d'alimentation du contrôleur ;
- [x] placer l'interverrouillage manuel `JP_GEN_5V` ;
- [ ] raccorder `AUX_PGOOD` à une fonction matérielle justifiée ;
- [ ] valider physiquement l'absence de retour de courant dans tous les états.

Le contrôle du 24 septembre 2026 laisse volontairement une erreur ERC sur la
feuille racine : `AUX_PGOOD` n'est pas encore consommé. Elle disparaîtra par un
raccordement réel au verrouillage matériel, pas par une exclusion ERC.

Critère de sortie : calculs sourcés, composants commandables et démarrage sûr
sur toute l'enveloppe vérifiée 10–80 V, avec un plafond absolu d'usage à 80 V.
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

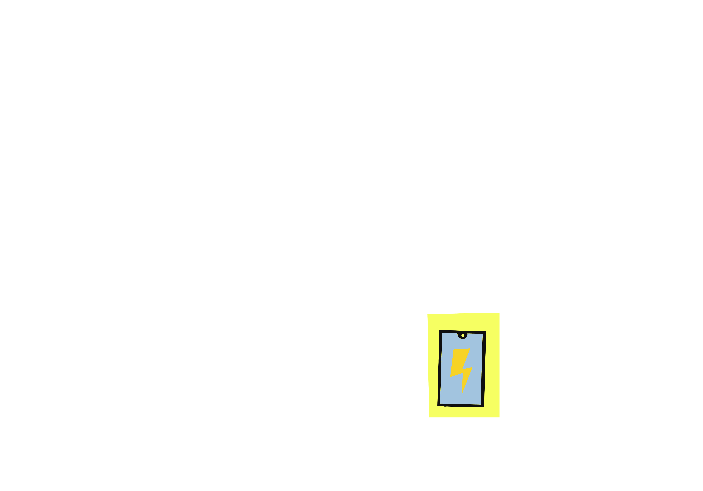
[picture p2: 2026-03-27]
webapp/bike-watts/assets/phone_on.png

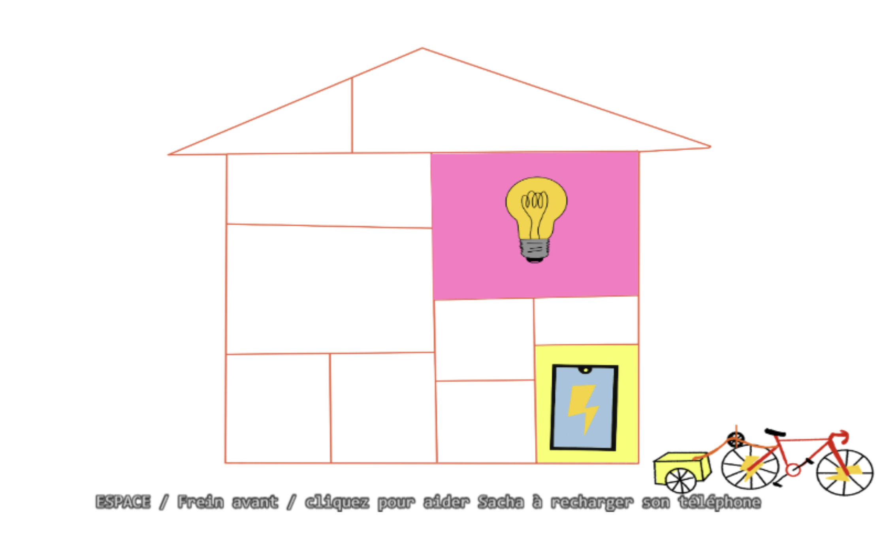
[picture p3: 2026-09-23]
webapp/bike-watts/assets/maison_gameplay_on.png

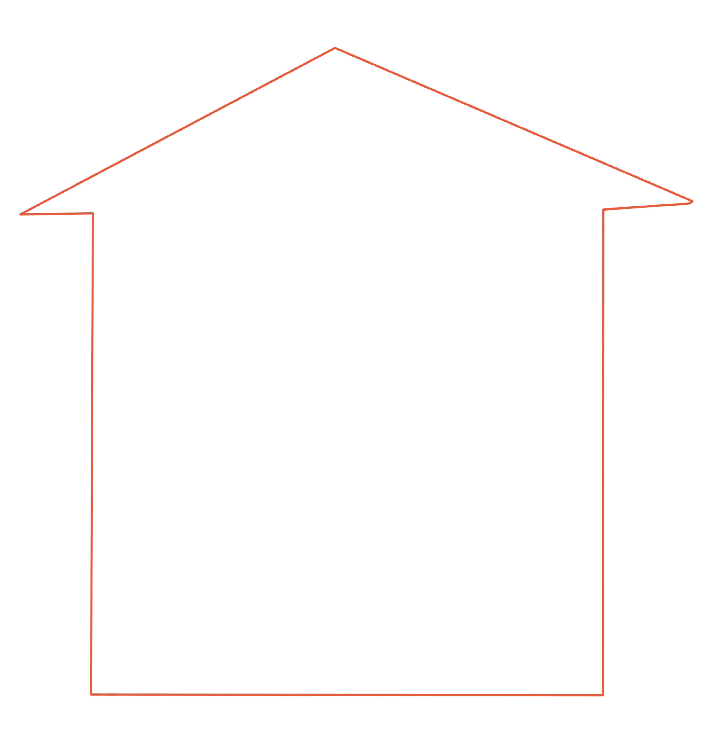
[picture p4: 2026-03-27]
webapp/bike-watts/assets/maison_vide.png

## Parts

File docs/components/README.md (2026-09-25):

# Component References

Quick-access links to all datasheets and product pages for every component used in the bike generator system.

---

## Microcontroller

| Component | Reference |
|---|---|
| **ESP32-C3** (RISC-V, Wi-Fi + BLE 5) | [Datasheet PDF](https://www.espressif.com/sites/default/files/documentation/esp32-c3_datasheet_en.pdf) · [Product page](https://www.espressif.com/en/products/socs/esp32-c3) · [Technical Reference Manual](https://www.espressif.com/sites/default/files/documentation/esp32-c3_technical_reference_manual_en.pdf) |

## Current Sensor

| Component | Reference |
|---|---|
| **ACS712 30A** Hall-effect current sensor | [Datasheet PDF](https://www.allegromicro.com/~/media/Files/Datasheets/ACS712-Datasheet.ashx) · [Allegro product page](https://www.allegromicro.com/en/products/sense/current-sensor-ics/zero-to-fifty-amp-integrated-conductor-sensor-ics/acs712) |

The ACS712 belongs to the current breadboard prototype. PCB V1 instead plans an
**INA228AIDGSR + external shunt** measurement stage before the buck:

| Component | References |
|---|---|
| **INA228** 85V I2C power monitor | [TI product page](https://www.ti.com/product/INA228) · [Datasheet PDF](https://www.ti.com/lit/ds/symlink/ina228.pdf) · [PCB V1 notes](../electrical/pcb-v1-ina228.md) |

## Digital Potentiometer

| Component | Reference |
|---|---|
| **DFR0520** breakout (embeds MCP42100) | [DFRobot wiki](https://wiki.dfrobot.com/Dual_Digital_Pot__100K__SKU__DFR0520) · [DFRobot schematic PDF](https://dfimg.dfrobot.com/62b2fb5caa613609f271523c/wiki/b2e1ba59af7c285a9d8e6542820bb53f.pdf) |
| **MCP42100** IC (100kΩ, 256 taps, SPI) | [Datasheet PDF](https://ww1.microchip.com/downloads/aemDocuments/documents/OTH/ProductDocuments/DataSheets/11195c.pdf) · [Microchip product page](https://www.microchip.com/en-us/product/MCP42100) |
| **MCP4151-104E/SN** PCB V1 (100kΩ, single channel, SPI) | [Microchip product page](https://www.microchip.com/en-us/product/MCP4151) · [Archived project notes](../../electrical/components/mcp4151-104/) |

## Energy Storage

| Component | Reference |
|---|---|
| **BLUETTI AC50S** 500Wh power station | [Product page](https://fr.bluettipower.eu/products/bluetti-ac50s-station-energie-portable) · [User manual PDF](https://www.hampshiregenerators.co.uk/wp-content/uploads/2022/03/Bluetti-PowerOak-AC50S-User-Manual.pdf) |

## DC/DC Converter

| Component | Reference |
|---|---|
| **400W CV/CC Buck module** | [Amazon listing](https://www.amazon.fr/dp/B0BLG7TN1C) |

## Dump Load

| Component | Reference |
|---|---|
| **G4 12V/20W halogen capsules** | [Amazon listing](https://www.amazon.fr/dp/B08YJTP2HW) |

## Wireless Button

| Component | Reference |
|---|---|
| **EnOcean PTM215B** BLE pushbutton | [Product page](https://www.enocean.com/en/products/enocean_modules_24ghz_ble/ptm-215b/) · [Datasheet PDF](https://www.enocean.com/wp-content/uploads/downloads-produkte/en/products/enocean_modules_24ghz_ble/ptm-215b/user-manual-pdf/PTM-215B-User-Manual.pdf) |

---

*See also: [Hardware Reference](../hardware.md) · [Firmware Architecture](../firmware.md)*

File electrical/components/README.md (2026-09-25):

# Component documentation

Store the authoritative documentation for every electrical component here.
Prefer manufacturer datasheets over reseller descriptions. Keep the original
PDF filename when practical and record its revision/date in this index.

Toute documentation utilisée pour confirmer un brochage, un boîtier, une
empreinte ou une limite électrique doit être copiée dans le dossier du
composant concerné. Chaque composant validé reçoit aussi un `README.md` qui
indique la source, la révision, les pages utilisées, le hash du fichier et la
correspondance broche physique → pin du symbole → pad du PCB.

## Prepared folders

| Folder | Component | Current status | Documents to add |
|---|---|---|---|
| [`ina228/`](./ina228/) | Texas Instruments INA228AIDGSR | pinout and footprint accepted for PCB V1 | TI datasheet archived; errata to add if published |
| [`current-shunt/`](./current-shunt/) | Bourns CSS4J-4026K-2L00F, 2 mΩ four-terminal shunt | référence et footprint natif figés pour PCB V1 | datasheet archivée ; land pattern et brochage Kelvin vérifiés |
| [`dfr0868-beetle-esp32-c3/`](./dfr0868-beetle-esp32-c3/) | DFRobot Beetle ESP32-C3 | V2.0 retenu ; empreinte porte-module socketée créée et affectée à U2 | schéma, datasheet, dimensions et CAD V1/V2 officiels archivés |
| [`dfr0520-mcp42100/`](./dfr0520-mcp42100/) | DFR0520 / MCP42100 | prototype breadboard historique, retiré du PCB V1 | documentation du module conservée |
| [`mcp4151-104/`](./mcp4151-104/) | Microchip `MCP4151-104E/SN` | référence PCB V1 retenue ; symbole et empreinte KiCad natifs | datasheet officielle archivée ; compatibilité avec le buck à mesurer |
| [`lm5164-aux-supply/`](./lm5164-aux-supply/) | Texas Instruments LM5164 | standard KiCad symbol pinout matches the datasheet; `LM5164DDAT` proposed; footprint not yet accepted | official TI datasheet archived; structured Konnect readback, Ultra Librarian package and power-stage values pending |
| [`jst-ph-battery-connector/`](./jst-ph-battery-connector/) | JST-PH 2 contacts, `S2B-PH-K-S(LF)(SN)` + `PHR-2` | famille choisie et empreinte KiCad standard affectée à `J6` | fiche JST archivée ; confirmer polarité et accessibilité physique |
| [`buck-b0blg7tn1c/`](./buck-b0blg7tn1c/) | generic CV/CC buck, Amazon B0BLG7TN1C | present, 60 × 60 × 45 mm recorded, exact controller unknown | source image, board photos, controller datasheet when identified |
| `acs712-legacy/` | ACS712 module | legacy prototype measurement | Allegro datasheet, module schematic, exact variant photo |
| `rectifier/` | three-phase bridge rectifier | exact reference to confirm | datasheet, pinout, thermal data |
| `bluetti-ac50s/` | BLUETTI AC50S | external energy sink | user manual, DC-input limits, connector information |
| `dump-load/` | G4 halogen branches | present or planned | lamp ratings, holders, thermal notes |
| [`connectors-and-protection/`](./connectors-and-protection/) | fuses, TVS and power connectors | provisional candidates documented | final choice after voltage/current measurements |

## Known online references

- INA228: <https://www.ti.com/product/INA228>
- INA228 datasheet: <https://www.ti.com/lit/ds/symlink/ina228.pdf>
- Beetle ESP32-C3: <https://www.dfrobot.com/product-2566.html>
- DFR0520: <https://wiki.dfrobot.com/dfr0520/>
- MCP4151: <https://www.microchip.com/en-us/product/MCP4151>
- LM5164: <https://www.ti.com/product/LM5164>
- LM5164 datasheet: <https://www.ti.com/lit/ds/symlink/lm5164.pdf>
- ACS712: <https://www.allegromicro.com/-/media/files/datasheets/acs712-datasheet.ashx>
- Buck listing: <https://www.amazon.fr/dp/B0BLG7TN1C>

## Naming convention

Use names such as:

```text
manufacturer_part-number_document_revision.pdf
manufacturer_part-number_land-pattern.pdf
module_front.jpg
module_back.jpg
measurements.md
```

Do not place credentials, order invoices or personal delivery information in
this versioned directory.

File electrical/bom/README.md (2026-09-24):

# Electrical BOM workspace

This directory will hold reviewed BOM snapshots and sourcing notes.

The KiCad schematic will ultimately be the source of truth for component
references and quantities. Files placed here are derived working artifacts and
must state the project revision or Git commit from which they were produced.

Suggested future files:

```text
bom-v1-working.csv
sourcing-notes.md
alternatives.csv
```

Current working snapshot:

- [`controller-v1-working.md`](./controller-v1-working.md) — logical controller
  sheets, known values and the decisions still blocking an order.

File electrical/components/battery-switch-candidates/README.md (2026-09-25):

# Interrupteur batterie — candidats

Les petits C&K OS/JS couverts par les empreintes KiCad natives sont écartés :
leur courant assigné de 0,1 à 0,3 A est trop faible face à la recharge et aux
pointes du Beetle.

Le candidat traversant actuel est le C&K `1101M2S3CQE2` : SPDT utilisé comme
SPST, contacts argent, assigné jusqu'à 6 A sous 28 VDC. Il favorise la soudure
manuelle et offre une marge confortable pour la batterie 1S.

Sources consultées le 25 septembre 2026 :

- fiche fabricant 1000 Series : <https://www.ckswitches.com/media/1429/1000.pdf>
- modèle tiers existant :
  <https://www.snapeda.com/parts/1101-M2S3CQE2/C%26K/view-part/>

## Décision V1 et validation ECAD

Le modèle SnapMagic/SnapEDA fourni le 25 septembre 2026 a été importé puis
comparé au dessin fabricant :

| Élément | Fiche C&K | Empreinte relue avec Konnect | Statut |
|---|---:|---:|---|
| Nombre de bornes | 3 | 3 | conforme |
| Entraxe 1–2 et 2–3 | 4,70 mm | 4,70 mm | conforme |
| Perçage | Ø1,85 mm | Ø1,85 mm | conforme |
| Pads | non imposés | Ø2,45 mm, anneau radial 0,30 mm | choix du modèle, acceptable V1 |
| Corps | 6,60 × 12,70 mm | `F.Fab` 6,60 × 12,70 mm | conforme |
| Courtyard | non imposé | 7,10 × 13,20 mm | marge 0,25 mm |

Correspondance retenue :

| Borne physique | Fonction dans le `1101` | Symbole V1 | Net |
|---:|---|---|---|
| 1 | contact position 1 | pin 1 du `SW_SPST` | `BAT_RAW` |
| 2 | commun | pin 2 du `SW_SPST` | `BAT_CTRL` |
| 3 | contact position 3 | absente du symbole fonctionnel | volontairement non connectée |

Le symbole SPST existant est conservé pour représenter l'usage réel. La
différence 2 pins / 3 pads est donc intentionnelle et documentée ; elle évite
de modifier les connexions existantes. L'empreinte est
`BikeGenerator:SW_1101M2S3CQE2`, placée en `S1` à proximité de `J6`.

Fichiers sources et empreintes SHA-256 :

- footprint SnapMagic téléchargé :
  `6D2C9BAED27D4F7CE07E57A597D246ADA6508EA12ECF3EF76EF1B9ABF04E327F` ;
- STEP SnapMagic téléchargé :
  `F010F9AD3A5417424098D642F92D4FEE7A968416C1FB72C95584FFBDA25EBD6B` ;
- symbole SnapMagic téléchargé, non utilisé :
  `96856AB1700C653160555E7C772D58A62BCA0EDB1824816F5BCC23C3E2BC14D3`.

La bibliothèque locale a reçu un `F.Fab` exact, un courtyard propre et
l'association au STEP. La mise à jour automatique d'une instance depuis cette
bibliothèque est actuellement refusée par Konnect à cause du champ historique
`tedit` du fichier SnapEDA. Cela n'affecte ni les pads ni la fabrication ; le
modèle 3D reste une aide visuelle à revalider dans l'éditeur d'empreintes.

La fiche officielle reste accessible par son URL mais son serveur refuse le
téléchargement automatisé (HTTP 403). Elle devra être enregistrée manuellement
dans ce dossier pour compléter l'archive locale.

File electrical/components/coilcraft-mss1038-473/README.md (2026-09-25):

# Coilcraft MSS1038-473MLC

Statut : **référence L1 validée pour la V1** de l'alimentation auxiliaire
LM5164.

## Affectation KiCad

- valeur : 47 µH ±20 % ;
- référence fabricant : `MSS1038-473MLC` ;
- empreinte : `Inductor_SMD:L_Coilcraft_MSS1038-XXX` ;
- modèle standard KiCad utilisé, sans empreinte personnalisée.

## Caractéristiques utilisées

- DCR maximale : 128 mΩ ;
- saturation : 1,6 A à −10 %, 1,98 A à −20 %, 2,22 A à −30 % ;
- courant thermique : 1,45 A pour +20 °C, 2,20 A pour +40 °C ;
- dimensions du corps : 10,0 × 10,2 × 3,8 mm.

Source officielle :
<https://www.coilcraft.com/en-us/products/power/shielded-inductors/ferrite-drum/mss-mos/mss1038/mss1038-473/>

## Document archivé

| Document | Révision / usage | SHA-256 |
|---|---|---|
| [`coilcraft-mss1038-datasheet.pdf`](./coilcraft-mss1038-datasheet.pdf) | document 378-1/378-2, révision 2022-09-27 ; caractéristiques et land pattern | `4A9750D3C3857C5E8D0C8CC6FCCC9321BA5E0FF2434F5E64D9BE742597EF3959` |

## Variante de réduction de coût

La Bourns `SRP1038C-470M` peut être moins chère et possède aussi une empreinte
KiCad standard. Elle n'est cependant pas recommandée pour les nouvelles
conceptions par Bourns. Elle est donc conservée comme piste d'optimisation BOM,
à réévaluer selon prix, disponibilité et cycle de vie, mais n'est pas montée par
défaut sur la V1.

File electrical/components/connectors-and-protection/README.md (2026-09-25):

# Connecteurs et protections — candidats V1

Statut : **candidats de présélection, non figés**.

| Fonction | Candidat | Motif principal | Condition avant validation |
|---|---|---|---|
| Fusible principal | calibre configurable ≤ 20 A, tension assignée ≥ 125 V DC | protège le trajet V1 limité à 20 A tout en restant compatible avec le plafond 80 V | choisir la courbe, le pouvoir de coupure et le calibre selon la génératrice |
| Porte-fusible principal | porte-fusible explicitement coté ≥ 125 V DC et compatible avec le fusible retenu | fusible remplaçable dans le faisceau | choisir longueur/section de câble et variante disponible |
| Fusible auxiliaire | Littelfuse `0449001.MR`, 1 A / 125 V, Slo-Blo | protège la branche LM5164 ; le déclassement continu de 25 % reste compatible avec le courant d'entrée calculé du LM5164 | empreinte exacte créée ; valider l'appel au démarrage |
| TVS bus | référence non figée ; empreinte SMCJ possible | écrêtage de transitoires courts uniquement | mesurer amplitude, durée, énergie et impédance de source ; DNP tant que la source n'est pas qualifiée |
| Connecteurs de puissance | Anderson Powerpole PP15/45 | famille documentée, jusqu'à 10 AWG, contacts PCB disponibles | choisir orientation, contacts et architecture faisceau/PCB |
| Câble puissance | 12 AWG minimum proposé, 10 AWG avec marge | enveloppe 20 A continue | longueur, température, groupement et isolant à confirmer |

## Décision V1 — bus 80 V et TVS

- `BUS_PROTECTED` est spécifié à **80 V maximum en continu**, transitoires
  tolérés compris dans ce plafond ; un fonctionnement durable au-dessus de
  80 V est hors spécification et peut endommager la carte ;
- l'INA228, limité à 85 V, reste le composant qui fixe cette enveloppe ;
- la TVS ne remplace ni cette limite d'emploi ni le fusible et n'est destinée
  qu'aux impulsions brèves ; aucun surge-stopper n'est ajouté en V1.

Il n'existe pas de TVS avalanche parallèle standard qui satisfasse
simultanément les deux contraintes très proches suivantes : rester garantie
quasi inactive jusqu'à 80 V et garantir un écrêtage inférieur à 85 V. À titre
de contrôle, une `SMCJ80A` admet 80 V de tension inverse permanente, mais son
avalanche ne commence qu'à 88,9 V minimum et sa tension de limitation annoncée
atteint 129 V au courant d'impulsion nominal : elle intervient trop tard pour
protéger l'INA228. À l'inverse, une `SMCJ51A` peut limiter à 82,4 V, mais n'est
prévue que pour 51 V permanents.

La `SMCJ48A` est donc retirée comme choix générique et aucune référence
universelle trompeuse ne la remplace. La V1 conserve un emplacement de TVS
optionnel ; sa référence sera adaptée à la première source après mesures. Une
source qui peut produire durablement plus de 80 V reste interdite, conformément
à la spécification acceptée.

Sources fabricants :

- [Littelfuse LP JCASE](https://www.littelfuse.com/~/media/files/littelfuse/technical%20resources/documents/product%20catalogs/lf_aftermarketcatalog_rev1_2015_lowres%20pdf.pdf)
- [Littelfuse HLJC](https://www.littelfuse.com/assetdocs/hljc-series-datasheet?assetguid=c6d82630-330b-41ea-b553-d50c31cd7f8f)
- [Littelfuse 449](https://www.littelfuse.com/assetdocs/fuses-449-datasheet?assetguid=7aef6e93-9808-456e-9bee-fba54271285f)
- [Littelfuse SMCJ](https://www.littelfuse.com/assetdocs/tvs-diodes-smcj-datasheet?assetguid=37388813-0d6d-4329-969b-1aa8b7614ac1)
- [Anderson PP15/45](https://www.andersonpower.com/content/dam/app/ecommerce/product-pdfs/PP1545/DS-PP1545.pdf)

## Documentation archivée

| Document | Usage | SHA-256 |
|---|---|---|
| [`anderson-pp1545-datasheet.pdf`](./anderson-pp1545-datasheet.pdf) | contacts câblés et PCB, courants, calibres de fils et références | `E82C8885EF9BCF147035AF45C575E062AB7A0EA30506E0D7BCACA5E615B6E4AE` |
| [`littelfuse-449-datasheet.pdf`](./littelfuse-449-datasheet.pdf) | caractéristiques électriques, dimensions et land pattern du `0449001.MR` ; copie miroir du document Littelfuse, le serveur fabricant refusant le téléchargement automatisé | `F60276A6F8DCF852C7E5BE37B73296D2B2AD692662B4229295AADC0137C88555` |
| [`littelfuse-smcj-datasheet.pdf`](./littelfuse-smcj-datasheet.pdf) | comparaison `SMCJ48A`, `SMCJ51A`, `SMCJ80A` et limites de clamp | `04C55B5C1641BD74C012EF8B3116444AAB9F5F9C6A11C497BD255BA910C2E172` |

Les PDF LP JCASE et HLJC sont liés ci-dessus, mais leur serveur a refusé
l'archivage automatisé. Ils devront être téléchargés manuellement dans ce
dossier si ces références sont acceptées définitivement.

## Empreinte du fusible auxiliaire

Le land pattern Littelfuse comporte deux pastilles de `1,96 × 3,15 mm`, un
intervalle cuivre de `2,95 mm` et un entraxe de `4,91 mm`. KiCad 10 ne fournit
pas d'empreinte native 6125/2410 exacte. L'empreinte locale
`BikeGenerator:Fuse_Littelfuse_0449001MR_6.10x2.69mm` reprend uniquement ces
dimensions, le corps nominal `6,10 × 2,69 mm` et un courtyard de
`7,37 × 3,65 mm` correspondant à l'enveloppe des pads augmentée de `0,25 mm`.
Elle n'embarque ni repère de polarité, ni modèle 3D. Aucun modèle ECAD exact
téléchargeable n'a été trouvé ; DigiKey ne propose actuellement qu'un modèle
3D pour cette référence.

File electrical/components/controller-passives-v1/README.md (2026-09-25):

# Passifs figés — contrôleur V1

Date de sélection : 25 septembre 2026.

Cette sélection applique la règle du projet : utiliser en priorité une
empreinte KiCad standard facile à souder à la main, puis retenir une référence
économique et disponible sans sacrifier les caractéristiques nécessaires.
Les prix sont des instantanés indicatifs de la base locale JLCPCB/LCSC.

## INA228, I²C et commande CC

| Références | Fabricant / MPN | LCSC | Caractéristiques | Empreinte KiCad |
|---|---|---|---|---|
| R1, R2 | Yageo `RC0805FR-0710RL` | `C96347` | 10 Ω, 1 %, 125 mW, 150 V | `Resistor_SMD:R_0805_2012Metric_Pad1.20x1.40mm_HandSolder` |
| R3, R4 | Yageo `RC0805FR-074K7L` | `C60816` | 4,7 kΩ, 1 %, 125 mW, 150 V | même empreinte |
| R5, R6 | Yageo `RC0805FR-0710KL` | `C84376` | 10 kΩ, 1 %, 125 mW, 150 V | même empreinte |
| C1, C3 | Yageo `CC0805KRX7R9BB104` | `C49678` | 100 nF, 50 V, X7R, 10 % | `Capacitor_SMD:C_0805_2012Metric_Pad1.18x1.45mm_HandSolder` |
| C2 | Yageo `CC0805KKX7R7BB105` | `C94122` | 1 µF, 16 V, X7R, 10 % | même empreinte |

## Alimentation auxiliaire LM5164

| Références | Fabricant / MPN | LCSC | Caractéristiques | Empreinte KiCad |
|---|---|---|---|---|
| C4, C5, C13 | Samsung `CL32Y106KCVZ4NE` | `C5596909` | 10 µF, 100 V, X7S, 10 % | `Capacitor_SMD:C_1210_3225Metric_Pad1.33x2.70mm_HandSolder` |
| C7, C8 | Samsung `CL32B226KOJNNNE` | `C55530` | 22 µF, 16 V, X7R, 10 % | même empreinte |
| C9 | Yageo `CC0805KRX7R9BB222` | `C107146` | 2,2 nF, 50 V, X7R, 10 % | 0805 condensateur HandSolder |
| C10 | Yageo `CC0805KRX7R9BB332` | `C107149` | 3,3 nF, 50 V, X7R, 10 % | 0805 condensateur HandSolder |
| C11 | Yageo `CC0805JRNPO9BN820` | `C113833` | 82 pF, 50 V, C0G/NP0, 5 % | 0805 condensateur HandSolder |
| R8 | Yageo `RC1206FR-0741K2L` | `C274076` | 41,2 kΩ, 1 %, 250 mW | `Resistor_SMD:R_1206_3216Metric_Pad1.30x1.75mm_HandSolder` |
| R9 | Yageo `RC0805FR-071ML` | `C107700` | 1 MΩ, 1 % | même empreinte |
| R10, R13 | Yageo `RC0805FR-07200KL` | `C114562` | 200 kΩ, 1 % | même empreinte |
| R11 | Yageo `RT0805BRD07316KL` | `C865397` | 316 kΩ, 0,1 %, 25 ppm/°C | même empreinte |
| R12 | Yageo `RT0805BRD07100KL` | `C122537` | 100 kΩ, 0,1 %, 25 ppm/°C | même empreinte |
| R14 | Yageo `RC0805FR-0747KL` | `C126351` | 47 kΩ, 1 % | même empreinte |

### Vérification de la capacité sous polarisation

Les courbes Samsung ont été relues, car la valeur inscrite sur un MLCC n'est
pas sa capacité réellement disponible sous forte tension continue.

- l'ancien `CL32B225KCJSNNE` perd typiquement 76,58 % à 80 V : deux pièces
  de 2,2 µF ne donnent qu'environ 1,03 µF effectif et ne satisfont pas le
  minimum de 2,2 µF demandé près de `VIN` par TI ;
- le `CL32Y106KCVZ4NE` perd typiquement 86,06 % à 80 V, mais sa valeur nominale
  de 10 µF laisse environ 1,394 µF par pièce ; trois pièces donnent environ
  4,18 µF à 25 °C ;
- même en appliquant ensuite une estimation conservatrice combinant la
  tolérance −10 % et l'extrémité négative X7S −22 %, il reste environ 2,94 µF.
  Cette combinaison est une estimation de conception, pas une garantie
  statistique fabricant ; elle sera contrôlée au prototype ;
- les deux `CL32B226KOJNNNE` de sortie perdent typiquement 23,41 % à 5 V et
  donnent encore environ 33,7 µF au total avant tolérance et température :
  leur choix reste valide.

Le remplacement d'entrée conserve exactement la même empreinte 1210 facile à
souder. Il ajoute seulement `C13` en parallèle et évite de faire dépendre la
stabilité du LM5164 du condensateur électrolytique, qui sert principalement à
l'amortissement des câbles.

Les pages fabricant archivées ci-dessous contiennent les données numériques
des courbes affichées :

| Fichier | Usage | SHA-256 |
|---|---|---|
| [`samsung-cl32b225kcjsnn-characteristics.html`](./samsung-cl32b225kcjsnn-characteristics.html) | preuve de l'insuffisance de l'ancien 2,2 µF à 80 V | `1DBA53A854EBFAF748095DAD41A95B7B7149F52A50EFDCFB0997776698457F15` |
| [`samsung-cl32y106kcvz4n-characteristics.html`](./samsung-cl32y106kcvz4n-characteristics.html) | courbe DC-bias du nouveau 10 µF / 100 V | `5BA08E31D29AC8626E4F04B654A8933493DE4228007166485E0A099B5FE8F00A` |
| [`samsung-cl32b226kojnnn-characteristics.html`](./samsung-cl32b226kojnnn-characteristics.html) | courbe DC-bias du 22 µF / 16 V de sortie | `CC36C3795F41E41EDF896F4F254FC2B812162203F7C54DAF8DD770E3CDA7D2AB` |

## Condensateur d'amortissement C6

Le choix V1 est le Panasonic `EEU-FC2A100` : 10 µF / 100 V, Ø6,3 ×
11,2 mm, pas 2,5 mm, 114 mA d'ondulation à 100 kHz et impédance maximale
1,8 Ω. Il utilise l'empreinte native
`Capacitor_THT:CP_Radial_D6.3mm_P2.50mm`, facile à souder à la main. Le Chengx
`KM106M100E11RR0VH2FP0` reste une variante économique possible, non retenue
faute de données fabricant aussi complètes.

## Sources

- [Samsung CL32B225KCJSNNE](https://product.samsungsem.com/mlcc/CL32B225KCJSNN.do)
- [Samsung CL32Y106KCVZ4NE](https://product.samsungsem.com/mlcc/CL32Y106KCVZ4N.do)
- [Samsung CL32B226KOJNNNE](https://product.samsungsem.com/mlcc/CL32B226KOJNNN.do)
- [Panasonic EEU-FC2A100](https://industrial.panasonic.com/ww/products/pt/aluminum-cap-lead/models/EEUFC2A100)
- [Yageo RC1206FR-0741K2L](https://www.digikey.com/en/products/detail/yageo/RC1206FR-0741K2L/731850)
- les URL de fiches Yageo/LCSC sont accessibles à partir des identifiants LCSC
  enregistrés directement dans le schéma KiCad.

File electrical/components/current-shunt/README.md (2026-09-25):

# Shunt de courant quatre bornes

Statut : **référence et empreinte PCB V1 retenues** ; validation thermique du
PCB et configuration INA228 encore requises avant fabrication.

## Référence V1

`Bourns CSS4J-4026K-2L00F`

- 2 mΩ ;
- quatre terminaux Kelvin ;
- tolérance ±1 % ;
- puissance 6 W à 70 °C ;
- TCR ±75 ppm/°C pour la référence 2 mΩ ;
- boîtier CMS 4026.

À 20 A : 40 mV et 0,80 W. À 25 A : 50 mV et 1,25 W. La plage
±163,84 mV de l'INA228 devra être utilisée pour couvrir 25 A.

La référence est indiquée active et disponible en bande coupée chez plusieurs
distributeurs lors de la vérification du 25 septembre 2026. Les prix et stocks
restent volatils ; vérifier de nouveau avant commande.

## Symbole, empreinte et correspondance Kelvin

KiCad 10 ne contient aucune empreinte nommée `CSS4J`. En revanche, son
empreinte native
`Resistor_SMD:R_Shunt_Isabellenhuette_BVR4026` reproduit exactement le land
pattern recommandé par Bourns et est donc réutilisée sans modification :

- pads de puissance : 2,55 × 5,60 mm ;
- pads Kelvin : 2,55 × 0,90 mm ;
- centres des colonnes : `x = ±4,025 mm` ;
- encombrement cuivre : 10,60 × 7,30 mm ;
- corps `F.Fab` : 10,10 × 6,675 mm pour un composant nominal
  10,06 × 6,60 mm ;
- courtyard, sérigraphie et modèle 3D présents.

Le dessin Bourns ne numérote pas les quatre terminaisons. La numérotation est
donc définie par la géométrie de l'empreinte, vue de dessus :

| Pad | Terminal physique | Pin du symbole `Device:R_Shunt` | Net V1 |
|---:|---|---:|---|
| 1 | force gauche | 1 | entrée après `F1` |
| 2 | sense gauche | 2 | `SHUNT_HI_K` |
| 3 | sense droite | 3 | `SHUNT_LO_K` |
| 4 | force droite | 4 | `BUS_PROTECTED` |

Cette correspondance a été relue après affectation à `R7`. Elle conserve les
deux pistes Kelvin séparées des pads de puissance. Le nom Isabellenhütte du
footprint ne désigne pas le composant acheté ; seule sa géométrie identique est
réutilisée pour le Bourns.

## Documentation archivée

| Document | Source | SHA-256 |
|---|---|---|
| [`bourns-css4j-4026.pdf`](./bourns-css4j-4026.pdf) | [Bourns](https://www.bourns.com/docs/product-datasheets/css4j-4026.pdf) | `27BE7941FF95AFC1C0A98AC573D33A987279CE2EE55985ED78308D502543E49D` |

Sources de disponibilité consultées :

- [DigiKey — CSS4J-4026K-2L00F](https://www.digikey.com/en/products/detail/bourns-inc/CSS4J-4026K-2L00F/6023759)
- [Mouser — CSS4J-4026K-2L00F](https://www.mouser.fr/en/ProductDetail/Bourns/CSS4J-4026K-2L00F)

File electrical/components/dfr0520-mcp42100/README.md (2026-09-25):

# DFR0520 / MCP42100-100 kΩ

Statut : **module historique du prototype sur breadboard**. Il n'est plus
utilisé sur le PCB V1, qui intègre directement un
[`MCP4151-104E/SN`](../mcp4151-104/README.md) simple canal. Cette page reste la
référence pour comprendre et maintenir le prototype existant.

## Documents archivés

| Document | Usage | SHA-256 |
|---|---|---|
| [`dfr0520-schematic-v1.0.pdf`](./dfr0520-schematic-v1.0.pdf) | schéma du module et brochage | `49E7C5F02FD9F11FA1A450C2902C5F48A2B5256A5DB370F28553F9005170C8BD` |
| [`dfr0520-dimension-v1.0.pdf`](./dfr0520-dimension-v1.0.pdf) | dimensions et entraxes | `396C0786F262C4763191BECBCA93DE936F37B0133F406093201E04881E38D925` |
| [`microchip-mcp41xxx-42xxx-11195c.pdf`](./microchip-mcp41xxx-42xxx-11195c.pdf) | limites électriques du MCP42100 | `F78338DBF59DDB8738867DA30E644D52942538192BCE9DFF070C4E765B679C1A` |

Sources officielles : [wiki DFRobot DFR0520](https://wiki.dfrobot.com/dfr0520/)
et [fiche Microchip MCP41xxx/42xxx](https://ww1.microchip.com/downloads/en/devicedoc/11195c.pdf).

## Brochage retenu dans la bibliothèque KiCad

Le symbole et l'empreinte projet utilisent une numérotation unique de 1 à 12.
En regardant le module par-dessus, texte lisible :

| Position physique | Pads KiCad | Signaux |
|---|---|---|
| rangée haute, de gauche à droite | 6, 5, 4, 3, 2, 1 | `VCC`, `GND`, `SI`, `CS`, `SCK`, `SO` |
| rangée basse, de gauche à droite | 7, 8, 9, 10, 11, 12 | `PA0`, `PW0`, `PB0`, `PA1`, `PW1`, `PB1` |

L'empreinte `BikeGenerator:DFR0520_Dual_Digital_Pot` est un module traversant
de 20 × 18 mm, avec deux rangées au pas de 2,54 mm séparées de 12,70 mm. Elle
comporte 12 pads de 1,8 mm percés à 1,0 mm, une cour et un repère de pad 1.

## Limites à respecter

- alimentation logique : 2,7 à 5,5 V ; V1 en 3,3 V ;
- `PAx`, `PWx` et `PBx` doivent rester entre `GND` et `VCC` ;
- courant dans chaque terminal analogique : inférieur à ±1 mA ;
- le module possède déjà ses condensateurs de découplage et maintient les
  entrées `RS` et `SHDN` à l'état haut ;
- ces limites concernent les trois fils de réglage, pas le chemin de puissance
  du générateur.

Avant de relier `J_CC_CTRL` au buck, mesurer les trois broches de son
potentiomètre d'origine dans les états arrêt, minimum et maximum. Une tension
hors de 0–3,3 V ou un courant supérieur à 1 mA imposera une interface isolée ou
analogique différente : le DFR0520 ne devra alors pas être raccordé directement.

## Intégration du prototype historique

- `U3` : module DFR0520 / MCP42100 100 kΩ ;
- `R6` : rappel de 10 kΩ sur `POT_CS` afin de garder le module désélectionné au
  démarrage ;
- SPI : `POT_MOSI`, `POT_MISO`, `POT_SCK`, `POT_CS` ;
- `J1` : broche 1 `CC_A`, broche 2 `CC_W`, broche 3 `CC_B` ;
- `TP9`, `TP10`, `TP11` : points de test des trois lignes analogiques ;
- `PA1`, `PW1`, `PB1` : explicitement non connectées.

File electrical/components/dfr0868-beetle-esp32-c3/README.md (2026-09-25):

# DFR0868 Beetle ESP32-C3

Statut : **DFR0868 V2.0 retenu pour la V1**. Les deux boutons visibles sur les
photos, le brochage et l'implantation concordent avec le CAD et le schéma V2.0
officiels. Une vérification au pied à coulisse reste prévue avant fabrication,
mais elle ne bloque plus la CAO.

## Documents archivés

| Document | Usage | SHA-256 |
|---|---|---|
| [`dfr0868-schematic-v2.0.0.pdf`](./dfr0868-schematic-v2.0.0.pdf) | schéma du module V2.0 | `767B6FE71168BF555BA4A948993EE45295E36217E1F26D4C678DEA7BC01528ED` |
| [`dfr0868-schematics-v1.0.zip`](./dfr0868-schematics-v1.0.zip) | archive DFRobot des schémas | `2E60C6A825E8BDF85AD5E3A55CC0F10560F1D623CAF93B299538CBD22D1ADCDF` |
| [`dfr0868-dimension-v1.0.pdf`](./dfr0868-dimension-v1.0.pdf) | dessin mécanique | `DCEF25759DAD3F71CE50D2156F906878A27B3D9E003EB66516BB2BABF3161DD0` |
| [`dfr0868-beetle-esp32-c3-cad-v1.0.zip`](./dfr0868-beetle-esp32-c3-cad-v1.0.zip) | CAD 2D officiel V1.0 et V2.0, DXF et PNG | `78A78D05F1D7A3CF139639193893DA8700EB33C44EA4CFB4E017198FBF1C69FB` |
| [`esp32-c3-mini-1-datasheet-v1.0.pdf`](./esp32-c3-mini-1-datasheet-v1.0.pdf) | module radio ESP32-C3-MINI-1 | `FA120B90244544BEF0188204AEB37434068E2F8066DAB4A1C23AFDB4E5B44E9A` |
| [`wurth-61300811821-socket-header.pdf`](./wurth-61300811821-socket-header.pdf) | socket femelle 1×8 retenu | `89F56F941E13061701076DCBE2F3D6B6ADCB568FF55407D16572E085C13D91A9` |
| [`wurth-61300811121-pin-header.pdf`](./wurth-61300811121-pin-header.pdf) | barrette mâle 1×8 candidate côté Beetle | `AC2B7013C4444914967474BBE451283F87704DF4F7229497E7EB98A746E36B4B` |

Sources officielles : [wiki DFRobot DFR0868](https://wiki.dfrobot.com/dfr0868/)
et [schéma V2.0](https://dfimg.dfrobot.com/nobody/wiki/d0e8b7f0f042c14f6959c3edc748053b.pdf).

## Radio et antenne

Le DFR0868 V2.0 documenté utilise un module `ESP32-C3-MINI-1`. Cette variante
possède une antenne PCB 2,4 GHz intégrée au module. Elle sert à la fois au Wi-Fi
802.11 b/g/n et au Bluetooth Low Energy ; l'ESP32-C3 gère leur coexistence sur
la même antenne. La variante `ESP32-C3-MINI-1U` serait au contraire destinée à
une antenne externe par connecteur RF, mais ce n'est pas la variante identifiée
sur le Beetle.

Conséquences pour le futur PCB porteur et le boîtier :

- placer de préférence l'extrémité antenne du Beetle au bord du PCB, voire en
  débord ;
- ne mettre ni cuivre, ni piste, ni composant sous ou devant la zone antenne ;
- éloigner le nœud de commutation `SW` du LM5164, l'inductance, les câbles de
  puissance, le dissipateur du buck et la batterie ;
- conserver si possible 15 mm de dégagement autour de l'antenne dans le
  boîtier, sans métal ;
- vérifier portée BLE et débit Wi-Fi dans le boîtier final.

Guide officiel : [placement des modules ESP32-C3 sur une carte
porteuse](https://docs.espressif.com/projects/esp-hardware-design-guidelines/en/latest/esp32c3/pcb-layout-design.html).

## Brochage du symbole projet

Vue de dessus du module, USB-C en haut :

| Pads symbole | Rangée | Signaux |
|---|---|---|
| 1 à 8 | gauche, de haut en bas | `GND_L`, `3V3`, `GPIO0`, `GPIO1`, `GPIO4`, `GPIO6`, `GPIO5`, `GPIO7` |
| 9 à 16 | droite, de haut en bas | `BAT`, `GND_R`, `VIN_5V`, `GPIO20_RX`, `GPIO21_TX`, `GPIO8`, `GPIO9_BOOT`, `GPIO2` |

## Empreinte porte-module V1

La recherche dans les bibliothèques KiCad installées ne retourne aucune
empreinte `DFR0868` ou `Beetle ESP32`. L'empreinte projet suivante a donc été
créée à partir du CAD DFRobot V2.0 archivé :

`BikeGenerator:DFR0868_Beetle_ESP32-C3_V2_Socketed`

Le module reste amovible sur deux barrettes femelles verticales 1 × 8 au pas de
2,54 mm. Ce choix favorise le soudage manuel et le remplacement du Beetle. Les
dimensions retenues sont :

- carte du module : 20,50 × 25,00 mm ;
- entraxe des deux rangées : 17,78 mm ;
- pas vertical : 2,54 mm ;
- premier centre à 2,65 mm du bord USB ;
- trous du module : Ø0,90 mm, information DFRobot ;
- trous du PCB porteur : Ø1,00 mm, pads Ø1,70 mm, géométrie reprise de
  `Connector_PinSocket_2.54mm:PinSocket_1x08_P2.54mm_Vertical`.

Le diamètre de 1,00 mm concerne les pattes des sockets sur notre PCB, pas les
trous Ø0,90 mm du Beetle. Le module devra recevoir deux rangées de broches mâles
compatibles ; leur insertion dans les trous du Beetle doit être essayée avant
commande en série.

La référence retenue pour les deux sockets du PCB est Würth Elektronik
`61300811821`, active, THT, 1 × 8, 2,54 mm, 3 A. Son dessin recommande des trous
de Ø1,02 ±0,15 mm : le perçage KiCad de 1,00 mm est cohérent. La barrette mâle
candidate côté Beetle est la Würth `61300811121`. Ses broches carrées nominales
de 0,64 mm rendent l'essai physique dans les trous Ø0,90 mm indispensable ; si
l'insertion est trop serrée, seule cette barrette mâle changera, pas l'empreinte
du PCB porteur.

Vue de dessus, USB-C en haut, coordonnées locales en millimètres :

| Pad | Signal | X | Y | Preuve |
|---:|---|---:|---:|---|
| 1 | `GND_L` | -8,89 | -9,85 | CAD V2, gauche haut |
| 2 | `3V3` | -8,89 | -7,31 | CAD V2 |
| 3 | `GPIO0` | -8,89 | -4,77 | CAD V2 |
| 4 | `GPIO1` | -8,89 | -2,23 | CAD V2 |
| 5 | `GPIO4` | -8,89 | 0,31 | CAD V2 |
| 6 | `GPIO6` | -8,89 | 2,85 | CAD V2 |
| 7 | `GPIO5` | -8,89 | 5,39 | CAD V2 |
| 8 | `GPIO7` | -8,89 | 7,93 | CAD V2, gauche bas |
| 9 | `BAT` | 8,89 | -9,85 | CAD V2, droite haut |
| 10 | `GND_R` | 8,89 | -7,31 | CAD V2 |
| 11 | `VIN_5V` | 8,89 | -4,77 | CAD V2 |
| 12 | `GPIO20_RX` | 8,89 | -2,23 | CAD V2 |
| 13 | `GPIO21_TX` | 8,89 | 0,31 | CAD V2 |
| 14 | `GPIO8` | 8,89 | 2,85 | CAD V2 |
| 15 | `GPIO9_BOOT` | 8,89 | 5,39 | CAD V2 |
| 16 | `GPIO2` | 8,89 | 7,93 | CAD V2, droite bas |

Les comptes concordent : 16 trous physiques, 16 pins du symbole et 16 pads de
l'empreinte, sans doublon. Le courtyard mesure 21,50 × 26,00 mm. Un rectangle
sur `Dwgs.User` rappelle la zone d'antenne : c'est un dégagement conservateur
de placement, pas une cote radio fournie par DFRobot. L'empreinte n'a pas de
modèle 3D. Elle est affectée à `U2` dans `mcu.kicad_sch`.

## Affectation V1

| Fonction | GPIO |
|---|---:|
| `I2C_SDA` | 0 |
| `I2C_SCL` | 1 |
| GPIO libre / extension | 4 |
| `POT_SCK` | 6 |
| `POT_CS` | 5 |
| `POT_MOSI` | 7 |
| `UART_RX` | 20 |
| `UART_TX` | 21 |
| `INA_ALERT` | 2 |

La feuille KiCad `MCU` raccorde maintenant :

- `AUX_5V` à `VIN_5V` par le cavalier amovible `JP3`, représenté
  provisoirement par un header traversant 1 × 2 au pas de 2,54 mm ;
- la batterie LiPo 1S protégée `801350`, 500 mAh, à `BAT` par `S1` ;
- la sortie 3,3 V du Beetle à l'INA228, au MCP4151 et aux interfaces logiques.

Le connecteur batterie `J6` utilise l'empreinte KiCad standard
`Connector_JST:JST_PH_S2B-PH-K_1x02_P2.00mm_Horizontal`. Le pad 1 est relié à
`BAT_RAW` et le pad 2 à `GND`. L'embase choisie est la
`S2B-PH-K-S(LF)(SN)` ; le côté câble est un boîtier `PHR-2` avec deux contacts
`SPH-002T-P0.5S`. L'accessibilité et surtout la polarité du connecteur réel
restent à vérifier. Voir
[`../jst-ph-battery-connector/README.md`](../jst-ph-battery-connector/README.md).

Le schéma officiel V2.0 montre que la broche externe `VIN_5V` est le même net
que `VUSB`, donc que le VBUS du connecteur USB-C. `VUSB` alimente à la fois le
chargeur TP4057 et, par D1, le régulateur 3,3 V. La batterie rejoint ce même
régulateur par le PMOS Q1. Ce point est détaillé dans
[`power-input-analysis.md`](./power-input-analysis.md).

Conséquence : `JP3` doit être **ouvert avant de connecter un PC en USB-C**. Une
diode ajoutée uniquement en série entre le LM5164 et `VIN_5V` ne supprimerait
pas le retour vers le connecteur USB, puisque le 5 V générateur continuerait à
élever le rail `VUSB` partagé. La V1 utilise donc un interverrouillage manuel
explicite, à valider physiquement avant tout essai simultané.

DFRobot annonce une charge maximale de 400 mA. Pour la cellule 500 mAh choisie,
cela représente 0,8 C. Cette valeur est plausible, mais la fiche exacte de la
cellule `801350` doit encore autoriser explicitement ce courant, puis le courant
réel du chargeur doit être mesuré.

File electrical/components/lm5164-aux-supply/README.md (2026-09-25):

# LM5164 — alimentation auxiliaire du contrôleur

Statut : **première passe schématique réalisée ; valeurs de puissance,
références physiques et DFM à valider avant schéma définitif**.

## Rôle dans le système

Le convertisseur auxiliaire alimente le contrôleur indépendamment du buck
principal 400 W. Son entrée est prélevée sur `BUS_PROTECTED`, après le fusible
principal et le shunt de mesure, et avant l'entrée du buck principal.

```text
Redresseur -> fusible -> shunt -> BUS_PROTECTED
                                  +-> buck principal -> sortie 24 V externe
                                  +-> F_AUX -> LM5164 -> 5 V -> Beetle ESP32-C3
```

Ce placement évite de faire dépendre le démarrage du contrôleur de la présence,
de la charge ou du réglage du buck principal. La consommation du contrôleur et
la recharge de sa batterie restent incluses dans la puissance mesurée par
l'INA228.

## Enveloppe de conception retenue

| Paramètre | Cible V1 | Statut |
|---|---:|---|
| Bus protégé | 80 V DC maximum continu | décidé ; fonctionnement durable > 80 V hors spécification |
| Plage vérifiée pour le 5 V | 10 à 80 V DC | le démarrage UVLO reste voisin de 9 V |
| Tenue du circuit intégré | 100 V | candidat LM5164 |
| Sortie | 5 V | décidée |
| Charge continue à garantir | au moins 600 mA | préliminaire |
| Capacité du convertisseur | 1 A maximum | candidat LM5164 |
| Batterie contrôleur | LiPo 1S protégée `801350`, 500 mAh | choisie par l'utilisateur ; fiche à vérifier |
| Chargeur | TP4057 présent sur le Beetle, 400 mA maximum annoncé | documenté DFRobot |

Le budget de 600 mA couvre environ 400 mA de recharge et la logique. Le circuit
est dimensionné autour d'un convertisseur 1 A afin de conserver une marge pour
les pointes radio, les capteurs, les voyants et un écran optionnel. La batterie
retenue devra autoriser explicitement un courant de charge de 400 mA dans sa
fiche technique.

## Candidat LM5164

Le LM5164 est un buck synchrone Texas Instruments :

- entrée spécifiée de 6 à 100 V ;
- courant de sortie jusqu'à 1 A ;
- MOSFETs high-side et low-side intégrés ;
- boîtier `DDA`, HSOIC-8 PowerPAD, environ 4,9 × 6 mm ;
- broches `EN/UVLO` et `PGOOD` ;
- pas de compensation de boucle externe ;
- faible consommation à vide.

La référence `LM5164DDAT` est retenue pour le prototypage : elle utilise le
même silicium et le même boîtier DDA que `LM5164DDAR`, mais en petite bande de
250 pièces au lieu d'une bobine de 2500.

KiCad 10 contient déjà le symbole `Regulator_Switching:LM5164DDA`. Son brochage
concorde avec la fiche TI ; aucun symbole personnalisé n'est nécessaire. Son
footprint associé par défaut présente toutefois un pad thermique plus petit que
le land pattern TI révisé en 2026 et cite un autre composant comme source. Un
autre footprint standard KiCad, explicitement basé sur `DDA0008B`, a donc été
retenu comme référence géométrique, relu avec Konnect et rendu dans un PCB
jetable. Une variante locale V1 conserve cette géométrie mais emploie six vias
Ø0,60 mm percés à Ø0,30 mm. Elle est affectée à U4 et passe le DRC de validation
sans erreur ; l'anneau de 0,15 mm et le traitement des vias sous pad restent à
confirmer avec le fabricant.
La comparaison complète est documentée dans
[`kicad-validation.md`](./kicad-validation.md).

Le pré-dimensionnement du bus protégé jusqu'à 80 V vers 5 V est détaillé dans
[`design-calculation.md`](./design-calculation.md). Les valeurs proposées y sont
explicitement marquées comme candidates jusqu'à validation par le calculateur
TI et sélection de références commandables. Les résistances, les condensateurs
et L1 sont maintenant figés pour la V1.

## Première implémentation KiCad

La feuille `AUX_SUPPLY` est maintenant présente dans le projet principal et
reçoit `AUX_IN_PROTECTED` depuis `POWER_PATH`. `AUX_5V` alimente désormais la
feuille `MCU` à travers `JP3`. `AUX_PGOOD` reste la seule sortie hiérarchique
non consommée.

Cette première passe comprend :

- U4 `LM5164DDAT` et son pad exposé relié à `GND` ;
- le pont UVLO 1 MΩ / 200 kΩ ;
- `RON` 41,2 kΩ en 1206 / 250 mW ;
- l'inductance L1 Coilcraft `MSS1038-473MLC`, 47 µH, avec l'empreinte KiCad
  standard `Inductor_SMD:L_Coilcraft_MSS1038-XXX` ;
- le pont de retour 316 kΩ / 100 kΩ pour la cible 5 V ;
- le bootstrap 2,2 nF ;
- le réseau d'injection Type-3 200 kΩ / 3,3 nF / 82 pF ;
- trois capacités céramiques d'entrée 10 µF / 100 V, corrigées après lecture
  de leur courbe DC-bias à 80 V, et les capacités de sortie validées à 5 V ;
- le condensateur électrolytique `C6`, Panasonic `EEU-FC2A100`, 10 µF / 100 V ;
- le pull-up de `PGOOD` vers 3,3 V ;
- les points de test `AUX_IN`, `AUX_5V`, `AUX_PGOOD` et `GND`.

La topologie suit la fiche TI, notamment le réseau Type-3 placé entre `SW`,
`AUX_5V` et `FB`. Le détail des références, des nets et des contrôles est dans
[`schematic-implementation.md`](./schematic-implementation.md).

## Composants périphériques attendus

Le circuit intégré seul ne constitue pas l'alimentation. Le schéma final devra
comprendre au minimum :

- trois condensateurs d'entrée céramique 10 µF / 100 V dont la capacité
  effective estimée reste supérieure au minimum TI à 80 V ;
- protection locale `F_AUX` immédiatement au départ de `BUS_PROTECTED` : le
  fusible principal du chemin 20 A ne protège pas une dérivation fine ;
- inductance dont la valeur, le courant de saturation et les pertes sont
  calculés pour 5 V et la fréquence retenue ;
- condensateurs de sortie ;
- pont de retour réglant précisément 5 V ;
- réseau `RON`, `EN/UVLO` et éventuellement filtrage de `PGOOD` ;
- protection TVS optionnelle choisie après mesure des transitoires ; aucune
  TVS parallèle standard ne peut garantir à la fois l'absence de conduction à
  80 V et un écrêtage sous la limite INA228 de 85 V ;
- aucun composant `D_AUX` séparé en V1 : une diode sur l'arrivée du LM5164
  n'isolerait pas le VBUS USB du Beetle ; l'interverrouillage manuel `JP3`
  reste donc la frontière d'isolation retenue ;
- cavalier `JP_GEN_5V` permettant d'isoler la source générateur pendant la
  programmation USB ;
- points de test `AUX_IN`, `AUX_5V`, `PGOOD` et `GND`.

Le circuit d'application 12 V / 1 A de la fiche TI est une référence de méthode,
pas une nomenclature à recopier aveuglément. L'inductance de 68 µH, les
résistances de retour et les condensateurs doivent être recalculés pour la
sortie 5 V et la charge réelle.

## Batterie, USB et états d'alimentation

- la batterie `BAT_CTRL` est raccordée à `BAT` du Beetle à travers un
  interrupteur mécanique ;
- interrupteur ouvert et vélo immobile : aucune décharge volontaire de la
  batterie ;
- batterie déconnectée et pédalage : l'alimentation auxiliaire peut démarrer le
  contrôleur automatiquement ;
- batterie connectée et pédalage : le générateur alimente la logique et le
  TP4057 peut recharger la batterie ;
- `JP_GEN_5V` est ouvert avant de brancher l'USB au poste de développement ;
- aucune source ne doit être court-circuitée à la masse pour la sélectionner.

Le schéma officiel du Beetle V2.0 confirme que `VIN_5V` et le VBUS USB-C sont
un même net `VUSB`. Une diode uniquement placée sur l'arrivée du LM5164 ne peut
donc pas empêcher le générateur d'élever le VBUS du connecteur. La V1 emploie
un interverrouillage manuel `JP3`, obligatoirement ouvert avant USB. Le détail,
la matrice d'états et les mesures requises sont documentés dans
[`../dfr0868-beetle-esp32-c3/power-input-analysis.md`](../dfr0868-beetle-esp32-c3/power-input-analysis.md).

## Séquence de démarrage et commande CC

L'alimentation auxiliaire doit permettre un démarrage indépendant du buck
principal, mais elle ne suffit pas à rendre la commande CC sûre. La cible est :

1. apparition de `BUS_PROTECTED` ;
2. établissement du 5 V auxiliaire ;
3. validation de `PGOOD` ;
4. établissement du 3,3 V et démarrage de l'ESP32 ;
5. programmation d'une valeur CC de repli sûre ;
6. autorisation matérielle de la commande CC ;
7. seulement ensuite, acceptation d'une consigne BLE.

`PGOOD` et un signal `MCU_READY` pourront participer au verrouillage. La méthode
exacte — `SHDN`, interrupteur analogique, relais ou réseau passif — dépend de la
caractérisation des trois bornes du potentiomètre CC. Une limite de sécurité ne
reposera pas uniquement sur le firmware.

## Documents archivés

| Document | Révision / usage | SHA-256 |
|---|---|---|
| [`ti-lm5164-snvsa-u4d.pdf`](./ti-lm5164-snvsa-u4d.pdf) | `SNVSAU4D`, février 2026 ; limites, boîtier et circuit d'application | `CCE03619FBE13951EEA47458CD45E140361637D8FEF32AE143B82B16D597E32D` |
| [`panasonic-eeu-fc-series.pdf`](./panasonic-eeu-fc-series.pdf) | série FC ; caractéristiques et dimensions de `EEU-FC2A100` | `42D91AE29AB6122DFE20974ABAD2EFD45D91A29337A73C5A5319616301B004F7` |

Sources officielles :

- <https://www.ti.com/product/LM5164>
- <https://www.ti.com/lit/ds/symlink/lm5164.pdf>

## Points restant à figer

- transitoires, énergie et impédance de source mesurés sur le premier bus redressé ;
- acceptation fabricant de l'anneau de 0,15 mm et du traitement des six vias
  thermiques Ø0,60/0,30 mm sous le pad exposé ;
- vérification complémentaire du calcul 5 V / 600 mA à 1 A dans l'outil TI ;
- TVS spécifique à la source et protection de branche exactes ;
- calibre et pouvoir de coupure DC de `F_AUX` ;
- fonctionnement simultané générateur, USB et batterie ;
- fiche de la batterie 801350 / 500 mAh et courant de charge admissible ;
- état CC passif lorsque le contrôleur n'est pas encore initialisé.

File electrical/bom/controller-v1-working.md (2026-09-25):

# Nomenclature de travail — contrôleur V1

Statut : **schéma en cours, non prêt à commander**. Le squelette de puissance
est représenté, mais le shunt, les protections, l'alimentation auxiliaire et
les connecteurs de fort courant ne sont pas encore sélectionnés physiquement.

| Références | Qté | Valeur / référence | Empreinte ou état |
|---|---:|---|---|
| U1 | 1 | INA228AIDGSR | `Package_SO:TSSOP-10_3x3mm_P0.5mm` |
| U2 | 1 | DFR0868 Beetle ESP32-C3 V2.0 | `BikeGenerator:DFR0868_Beetle_ESP32-C3_V2_Socketed` ; deux sockets femelles 1×8, 2,54 mm, entraxe 17,78 mm |
| U2-SKT | 2 | Würth `61300811821`, socket femelle 1×8, 2,54 mm, THT, 3 A | géométrie native KiCad 1×8 intégrée dans l'empreinte U2 ; perçage 1,00 mm |
| U2-HDR | 2 | Würth `61300811121`, barrette mâle 1×8, 2,54 mm, THT | candidate à souder au Beetle ; confirmer l'insertion des broches 0,64 mm dans ses trous Ø0,90 mm |
| U3 | 1 | Microchip `MCP4151-104E/SN`, 100 kΩ, simple canal | `Package_SO:SOIC-8_3.9x4.9mm_P1.27mm` |
| R1, R2 | 2 | Yageo `RC0805FR-0710RL`, 10 Ω, 1 % | `Resistor_SMD:R_0805_2012Metric_Pad1.20x1.40mm_HandSolder` |
| R3, R4 | 2 | Yageo `RC0805FR-074K7L`, 4,7 kΩ, 1 % | même empreinte 0805 HandSolder |
| R5, R6 | 2 | Yageo `RC0805FR-0710KL`, 10 kΩ, 1 % | même empreinte 0805 HandSolder |
| C1, C3 | 2 | Yageo `CC0805KRX7R9BB104`, 100 nF, 50 V, X7R | `Capacitor_SMD:C_0805_2012Metric_Pad1.18x1.45mm_HandSolder` |
| C2 | 1 | Yageo `CC0805KKX7R7BB105`, 1 µF, 16 V, X7R | même empreinte 0805 HandSolder |
| C12 | 1 | Yageo `CC0805KRX7R9BB104`, 100 nF, 50 V, X7R, découplage local de U3 | `Capacitor_SMD:C_0805_2012Metric_Pad1.18x1.45mm_HandSolder` |
| JP1, JP2 | 2 | cavalier de soudure 3 pads | pont 1–2 fermé par défaut vers GND |
| J1 | 1 | `J_CC_CTRL`, 1×3, 2,54 mm | empreinte générique provisoire |
| J2 | 1 | `J_DISPLAY_I2C`, 1×4, 2,54 mm | empreinte générique provisoire |
| J3 | 1 | `J_DEBUG_UART`, 1×4, 2,54 mm | empreinte générique provisoire |
| TP1–TP11 | 11 | points de test | empreinte à revoir avant placement PCB |
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

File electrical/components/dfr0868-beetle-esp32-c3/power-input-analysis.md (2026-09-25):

# DFR0868 V2.0 — USB, VIN et batterie

Date d'analyse : 24 septembre 2026.

## Conclusion

Sur le schéma officiel du DFR0868 V2.0, la broche externe appelée `VIN_5V`
dans notre symbole correspond au net `VUSB`. Ce net est directement commun au
VBUS du connecteur USB-C.

Il ne faut donc jamais fermer le cavalier générateur `JP3` pendant que le port
USB-C est relié à un ordinateur. Le 5 V du LM5164 pourrait sinon être renvoyé
vers le VBUS du PC, tandis que l'alimentation USB et le LM5164 seraient reliés
en parallèle sans partage de courant maîtrisé.

## Chemin interne démontré par le schéma DFRobot

```text
USB-C VBUS ---- VUSB ----+---- TP4057 ---- BAT ---- Q1 PMOS ----+---- RT9080 ---- 3V3
                         |                                      |
                         +---------------- D1 -------------------+

Broche VIN_5V ----------- VUSB
Broche BAT -------------- BAT
```
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

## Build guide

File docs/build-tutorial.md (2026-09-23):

# Build Your Own Power-Generating Smart Trainer

> Turn a scooter motor and a stationary bike into an electricity-generating
> trainer using the standard Bluetooth FTMS interface. Zwift and TrainerDay
> control have been verified; other clients should be tested individually.

This guide walks you through the full build — from sourcing parts to your first
Zwift ride — designed for anyone with basic soldering skills.
The whole project can be built almost entirely from second-hand components.

**Estimated build time:** 2–4 weekends
**Cost (new parts):** ~€150–200
**Cost (second-hand):** ~€50–80
**Required skill level:** Basic soldering, can read a wiring diagram

---

## The Core Idea

Most home trainers consume electricity. This one **generates it**.

You pedal → a motor acts as a generator → a DC/DC converter regulates the output
to 24V → a power station charges. At a steady 100W effort you produce enough to
meaningfully charge a 500Wh battery station.

At the same time, a small microcontroller (ESP32-C3) measures power in real time,
controls resistance electronically, and talks to cycling apps over Bluetooth using
the standard FTMS protocol. From the app's perspective it exposes the same core
service and control commands as a commercial smart trainer, while its sensing and
resistance behaviour remain those documented for this prototype.

Surplus power beyond what the battery can absorb is safely burned off by halogen
lamps — which also provide a useful baseline braking force.

---

## 1. Parts List

### Core components

| Component | Role | Where to find second-hand | Approx. new price |
|---|---|---|---|
| Stationary exercise bike | Frame + pedals | Leboncoin, Vinted, FB Marketplace | €0–30 |
| **Brushless scooter motor** 24–36V 250–500W | Generator | Scooter repair shops, Leboncoin | €15–40 |
| **3-phase bridge rectifier** KBPC5010 50A/1000V | AC→DC | AliExpress, eBay | €3–5 |
| **400W CV/CC buck module** | Regulated 24V + current limit | AliExpress | €12–18 |
| **BLUETTI AC50S** or any 24V-input power station | Battery sink | FB Marketplace, eBay | €150–250 s/h |
| **ESP32-C3 Beetle** (DFRobot) | Microcontroller | AliExpress, DFRobot | €8–12 |
| **DFR0520** (MCP42100 digipot breakout) | Programmable resistance | DFRobot | €8 |
| **ACS712 30A** module | Current sensor | AliExpress | €2–3 |
| Resistors **100kΩ + 7.5kΩ** (¼W) | Voltage divider | Any electronics shop | <€1 |
| **G4 12V/20W halogen capsules** × 4+ | Dump load | Amazon, hardware store | €5–8/pack |
| G4 lamp holders (ceramic) | Lamp mounting | AliExpress | €3–5 |
| **EnOcean PTM215B** BLE button *(optional)* | Wireless resistance control | EnOcean distributors | €25 |
| Small enclosure | Electronics box | Hardware store / 3D printed | €5–10 |
| Wire 1.5mm² (bus) + 0.5mm² (signal) | Wiring | Hardware store | €5 |
| XT60 or Anderson connectors | Bus connections | AliExpress | €3 |
| 10A automotive fuse + holder | Bus protection | Auto shop | €2 |

---

## 2. System Overview

```
[Rider pedaling]
       |
       v
[Scooter motor — 3-phase AC out]
       |
       v
[3-phase bridge rectifier — unregulated DC]
       |
       v
[DC/DC Buck module — 24V regulated]
[Current limit pot = pedaling resistance]
       |
       +-----------------------------+
       v                             v
[BLUETTI DC input — up to 120W]  [Halogen lamps — ~40W/pair]
                                  (dump load + baseline braking)
       |
[ESP32-C3]
  measures V, I, power
  controls resistance via SPI digipot
  streams data over BLE (FTMS protocol)
```

**The resistance mechanism:** the buck module has a CC (constant-current) trim pot
that sets how much current the load can draw — i.e. how hard pedaling feels.
We replace this trim pot with a digital potentiometer (DFR0520) so the ESP32 can
change resistance at any time in response to your app or button press.

---

## 3. Mechanical: Mounting the Motor

This is the most variable part — it depends on your specific bike and motor.

*[Photo placeholder — motor mounted on the bike]*

### Goal

The motor shaft must rotate when you pedal. Common approaches:

- **Belt drive from the flywheel** — timing belt or V-belt from flywheel to motor
  shaft. Works well with hub motors. Requires a printed or machined pulley.
- **Direct coupling** — rigid coupling collar joining motor shaft to flywheel
  spindle. Clean but requires a machined adapter.
- **Chain drive** — sprocket on motor shaft + chain from rear sprocket.

### Key requirements

- **Gear/belt ratio ~3:1 to 5:1** — scooter hub motors are designed for 200–400 RPM;
  a typical flywheel at 70 RPM cadence needs a ratio to reach their generation range.
- **Motor held rigidly** — any wobble causes noise and bearing wear.
- **Phase order doesn't matter** — for a generator you can swap any two of the
  three motor wires without affecting operation.

> Scooter hub motors from scrapped electric kick scooters are ideal —
> common, cheap, robust, right voltage range.

---

## 4. Power Path Wiring

### 4.1 Motor → Rectifier

Connect the 3 motor wires to the 3 AC inputs of the bridge rectifier.

```
Motor wire 1 --> AC1
Motor wire 2 --> AC2    (KBPC5010 3-phase bridge)
Motor wire 3 --> AC3
                 (+) --> Bus positive
                 (-) --> Bus ground
```

Mount the rectifier on a metal surface or add a heatsink — it gets warm.

### 4.2 Rectifier → Buck Module

```
Rectifier (+) --[10A fuse]-- Buck IN+
Rectifier (-) -------------- Buck IN-
```

**Set the buck module output to 24V** using the CV trim pot before connecting
anything to the output. Measure with a multimeter — 24.0V ±0.2V with no load.

> ⚠️ Do this before connecting the BLUETTI. Overvoltage on its DC input is bad.

### 4.3 Buck Module → Loads

```
Buck OUT+ --+-- XT60 connector --> BLUETTI DC input (+)
            +-- Dump load chain --> Bus ground

Buck OUT-  --> BLUETTI DC input (-) / Dump load chain end
```

Use 1.5mm² wire minimum for the bus. Keep runs short.

### 4.4 Dump Load — Halogen Lamps

Each pair = 2× G4 12V/20W capsules **in series** across 24V:

```
Bus+ --[lamp A 12V/20W]--[lamp B 12V/20W]-- Bus-
```

Each pair dissipates ~40W. Wire pairs in parallel to increase dump power:

| BLUETTI max | Halogen pairs | Total headroom |
|---|---|---|
| 120W | 2 pairs (80W) | 200W |
| 120W | 3 pairs (120W) | 240W |

Mount lamps in **ceramic G4 holders**. Surface temperature ~250°C — keep away
from plastics. Ensure airflow.

---

## 5. The Tricky Part: Modifying the Buck Converter

This is the most demanding step. Read all the way through before starting.

*[Photo placeholder — buck module PCB with CC pot marked]*

### Why

The buck module has two trim pots:
- **CV pot** — sets output voltage → leave at 24V, never touch it again
- **CC pot** — sets the current limit → this becomes our resistance control

By replacing the CC pot with the DFR0520 digital potentiometer, the ESP32 can
change resistance in real time.

### Step 1 — Identify the CC pot

Two small blue multi-turn trimmer pots on the PCB. The CC one is usually labeled.
If unlabeled: carefully turn one to minimum — if the bike becomes very easy to
pedal (low current limit), that is the CC pot. If output voltage drops, put it
back — that was the CV pot.

*[Photo placeholder — CC pot identified with arrow]*

### Step 2 — Desolder the CC trimpot

Use solder wick or a desoldering pump to cleanly remove the 3-pin trimpot.
The three pads exposed are:
- **A** — one end of the resistive track
- **W** — wiper (center tap)
- **B** — other end of the resistive track

*[Photo placeholder — desoldered pads labeled A/W/B]*

### Step 3 — Wire the DFR0520

The DFR0520 has two pots (POT0 and POT1). We use **POT0**:
`A0, W0, B0` pins on the breakout.

```
Buck PCB pad A --> DFR0520 POT0 A0
Buck PCB pad W --> DFR0520 POT0 W0
Buck PCB pad B --> DFR0520 POT0 B0
```

Use short wires (5–10 cm).

> **Low-invasive alternative:** leave the original pot in place and wire the
> DFR0520 in parallel with it. This changes the effective resistance range —
> adjust `POT_CAL_POWER` in `config.h` after measuring real watts.

### Step 4 — Bench test

Before closing everything up:
- Power the ESP32 from USB only
- Open Serial Monitor at 115200 baud
- Check for `[DIGIPOT]` messages confirming SPI writes
- Spin the motor by hand and verify that changing the digipot value
  changes the braking torque you feel

---

## 6. Sensor Wiring

### 6.1 ACS712 — Current Sensor

Wire in-line with the bus current path (all load current passes through it):

```
Buck OUT+ --> [ACS712 IP+]--[ACS712 IP-] --> loads

ACS712 VCC  --> 3.3V (ESP32)
ACS712 GND  --> GND
ACS712 OUT  --> GPIO0 (ESP32)
```

> ⚠️ At first boot the firmware spends ~1 second calibrating the zero-current
> baseline. Make sure **no current is flowing** through the ACS712 at that moment
> (bus disconnected from loads). If current flows during calibration, all power
> readings will be offset.

### 6.2 Voltage Divider — Bus Voltage Sensor

Two resistors scale 24V down to ≤3.3V for the ADC. See
[voltage-divider.md](voltage-divider.md) for the full explanation.

```
Bus (+) --[R1 = 100kΩ]--+--[R2 = 7.5kΩ]-- GND
                         |
                       GPIO1 (ESP32)
```

- At 24V → GPIO1 = 1.67V ✅
- At 40V → GPIO1 = 2.79V ✅ (safe across the BLUETTI input range)

Build on a small perfboard strip inside the electronics box.

---

## 7. Electronics Box

All control electronics in one small enclosure near the buck module.

**Contents:**
- ESP32-C3 Beetle
- DFR0520 breakout
- ACS712 board
- Voltage divider (2 resistors on a perfboard strip)
- Screw terminals or JST connectors for external wires

**Internal wiring:**

| Signal | From | To |
|---|-----|----|
| 3.3V | ESP32 3V3 | ACS712 VCC, DFR0520 VCC |
| GND | ESP32 GND | ACS712 GND, DFR0520 GND, R2 bottom |
| GPIO0 | ESP32 | ACS712 OUT |
| GPIO1 | ESP32 | R1/R2 junction |
| GPIO5 CS | ESP32 | DFR0520 CS |
| GPIO6 SCK | ESP32 | DFR0520 SCK |
| GPIO7 MOSI | ESP32 | DFR0520 SI |

External cables out of the box:
- Bus V+ and V− for voltage divider
- ACS712 current path (bus current through sensor)
- SPI cable to DFR0520 → to buck CC pads
- USB-C for flashing and serial monitor

*[Photo placeholder — inside electronics box]*

---

## 8. Flashing the Firmware

### Install Arduino IDE + ESP32 support

1. Download **Arduino IDE** from arduino.cc
2. Preferences → add to "Additional boards manager URLs":
   `https://raw.githubusercontent.com/espressif/arduino-esp32/gh-pages/package_esp32_index.json`
3. Tools → Boards Manager → search "esp32" → install **esp32 by Espressif Systems**

### Flash

1. Board: **ESP32C3 Dev Module**
2. Select the COM port that appears when plugging in via USB-C
3. Upload → open Serial Monitor at **115200 baud**

Expected output:
```
[SENSORS] ACS712 midpoint: 1650 mV (1.650V)
[RESISTANCE] Ready
[BLE] FTMS service started. Advertising as "ESP32 Bike Trainer"
[BUTTON] Scanning started
```

---

## 9. EnOcean Button Pairing (Optional)

The **PTM215B** is a self-powered (no battery) BLE button for wireless resistance
control — press left (-) or right (+) without a phone.

**Find its MAC address:**
1. Install **nRF Connect** (free, iOS / Android)
2. Press either button → it appears in the scan list
3. Note the MAC address (format: `XX:XX:XX:XX:XX:XX`)

**Set it in config.h:**
```c
#define ENOCEAN_MAC_0   0xAB   // replace with your actual bytes
#define ENOCEAN_MAC_1   0xCD
// ... etc
```
Reflash after editing.

---

## 10. Calibration

### Voltage divider

With bus powered, compare Serial Monitor vs multimeter:
```
ADC volt: Vpin=1.67V  bus=24.0V
```
If they differ by more than 0.5V, adjust `VDIV_OFFSET_V` in `config.h`.

### Wiper-to-power (most important for ERG accuracy)

1. Temporarily fix the digipot: add `Resistance_Set(30, "cal");` in `setup()`
2. Flash. Ride steadily for 30 seconds. Note stable power in Serial Monitor:
   `Power: 118.3W`
3. Update `config.h`:
   ```c
   #define POT_CAL_VALUE   30
   #define POT_CAL_POWER   118.0f
   ```
4. Remove the temporary line and reflash.

---

## 11. First Ride — Connecting an App

**Zwift:** Pair Devices → search "ESP32 Bike Trainer" → pair as Power Source
and Controllable Trainer.

**Other FTMS applications:** pair the same way, but record each application and
version as tested before advertising compatibility.

**Without an app:** bike stays in Manual mode. Use the EnOcean button to step
resistance up/down. Status is logged every 10 seconds on Serial Monitor.

---

## 12. Troubleshooting

| Symptom | Cause | Fix |
|---|---|-----|
| Power reads 0W | Voltage divider not wired | Wire R1+R2 to GPIO1 |
| Power reads wrong | ACS712 calibrated with current flowing | Restart ESP32 with bus disconnected |
| BLE not visible | ESP32 not running | Check Serial Monitor for errors |
| Resistance doesn't change | SPI issue | Check GPIO5/6/7 wiring; look for [DIGIPOT] in serial |
| Buck shuts down | Overcurrent | Reduce digipot value; check 10A fuse |
| Lamps flicker | Cold filament inrush | Normal — stabilizes after ~5s |

---

## 13. Extending the System

- **Real cadence sensor** — reed switch or Hall sensor on the crank
- **More dump load** — add halogen pairs in 40W steps for stronger riders
- **OLED display** — I2C screen showing live V, I, W, BLE status
- **Game / simulation** — the BLE API is fully open. See [ble-api.md](ble-api.md)

---

## 14. Safety

- **Always fuse the bus at 10A**
- **Halogen lamps run at ~250°C** — ceramic holders, metal panels, ventilation
- **ACS712 must have no current at boot** for auto-calibration
- **GPIO pins: 3.3V absolute maximum** — the 100kΩ/7.5kΩ divider remains below 3.3V up to approximately 47V
- **BLUETTI DC input: check polarity** — no reverse polarity protection
- **24V bus is not mains-isolated** — do not touch bus wiring and mains simultaneously

---

*See also: [Hardware Reference](hardware.md) · [Firmware Architecture](firmware.md) · [BLE API Reference](ble-api.md) · [Component References](components/README.md)*

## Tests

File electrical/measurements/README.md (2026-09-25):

# Measurements workspace

Use this directory for the characterization campaign that must precede the
final schematic and PCB routing.

- `raw/`: immutable source readings, serial captures and instrument exports;
- `photos/`: wiring, markings, probe locations and thermal-test photos;
- `processed/`: cleaned tables, plots and derived results.

The required measurement list is maintained in
[`docs/electrical/measurement-campaign.md`](../../docs/electrical/measurement-campaign.md).
The provisional values that allow PCB work to continue, plus the short
validation checklist for the first generator/buck pair, are in
[`first-generator-buck-validation-plan.md`](./first-generator-buck-validation-plan.md).

Each measurement set should state:

- date and test configuration;
- instrument and range;
- probe locations and polarity;
- battery and dump-load state;
- digipot/wiper setting;
- cadence or generator speed when applicable;
- raw value, unit and estimated uncertainty.

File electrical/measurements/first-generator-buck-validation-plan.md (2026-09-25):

# Hypothèses de conception et mesures du premier montage

Ce document sépare les **limites génériques de la carte**, utilisées pour
poursuivre la CAO, des **estimations du premier montage**, qui seront remplacées
par les mesures physiques. Une estimation n'est pas une spécification de la
génératrice.

## Enveloppe générique V1 déjà retenue

| Paramètre | Valeur de conception |
|---|---:|
| Bus protégé utilisable | 10 à 80 V DC |
| Démarrage auxiliaire estimé | 8,56 à 9,46 V, 9,0 V nominal |
| Plafond continu et transitoire toléré | 80 V |
| Courant du trajet principal | 20 A continu, 25 A bref |
| Alimentation logique | 5 V, 600 mA attendu, étage dimensionné jusqu'à 1 A |

La carte n'impose pas une puissance unique. Exemples idéalisés à 400 W :

| Tension bus | Courant correspondant |
|---:|---:|
| 10 V | 40 A, donc hors enveloppe 20 A |
| 20 V | 20 A, limite continue de la carte |
| 36 V | 11,1 A |
| 48 V | 8,3 A |
| 60 V | 6,7 A |
| 80 V | 5,0 A |

La carte couvre donc des sources différentes, mais leur puissance exploitable
reste limitée par la plus faible limite parmi la génératrice, le redresseur, la
carte 20 A, le buck principal et la charge.

## Estimations temporaires du premier montage

| Grandeur | Estimation de travail | Usage immédiat |
|---|---:|---|
| tension chargée | 36 V observés | point d'essai nominal |
| courant vers 350 W | 9,7 A | ordre de grandeur |
| courant vers 400 W | 11,1 A | dimensionnement du premier essai |
| tension à vide à cadence comparable | 45 à 60 V | estimation seulement |
| excursion rapide provisoire | 60 à 70 V | reste sous le plafond carte de 80 V |
| tension du réglage CC | probablement 0 à 1,25/2,5 V | hypothèse de compatibilité, pas autorisation de raccordement |
| courant du réglage CC | probablement quelques dizaines de µA | cohérent avec un potentiomètre de 100 kΩ |

La **tension à vide** signifie : génératrice entraînée, mais sortie électrique
déconnectée. Une génératrice immobile donne bien environ 0 V, mais ce n'est pas
la mesure à vide utile au dimensionnement.

Ces estimations permettent de conserver le schéma 10–80 V, le shunt 2 mΩ et le
LM5164 existants. Elles ne permettent pas de choisir une TVS universelle : la
TVS reste DNP par défaut et sera adaptée à la source après mesure de l'amplitude,
de la durée et de la répétition des pics.

## Mesures à réaliser sur la première génératrice

1. Tension DC au repos, puis à vide en pédalage lent, normal et rapide.
2. Tension chargée aux mêmes allures, avec la charge habituelle.
3. Courant chargé ; préférer une pince DC ou le shunt prévu. Ne pas placer un
   multimètre ordinaire en série sur un trajet proche de 10–20 A sans vérifier
   son calibre, son fusible et ses cordons.
4. Avec un oscilloscope et une sonde adaptés, maximum, durée et répétition des
   pics lors d'un démarrage rapide et d'une déconnexion de charge.

Ces valeurs qualifient la première source et son fusible/sa TVS ; elles ne
redéfinissent pas l'enveloppe générique 10–80 V de la carte.

## Mesures à réaliser sur le réglage CC du buck

Le raccordement direct du MCP4151 est autorisé seulement si les trois bornes du
potentiomètre du buck restent entre 0 et 3,3 V par rapport à `VIN-`, et si le
courant de borne reste largement inférieur à ±2,5 mA.

1. Buck hors tension : résistance entre chaque paire des trois broches du
   potentiomètre, aux positions minimum, milieu et maximum.
2. Buck alimenté sans pédalage puis sous charge : tension de chaque broche par
   rapport à `VIN-`, aux mêmes trois positions.
3. Identifier les deux broches réellement reprises par les deux fils actuels et
   déterminer si le montage utilise le potentiomètre en rhéostat.
4. Vérifier si `VIN-`, la masse logique du réglage CC et `GND` de la carte sont
   réellement communs.

L'hypothèse provisoire est un réglage bas potentiel, 0 à 2,5 V environ, avec un
courant de quelques dizaines de microampères. Si les mesures contredisent cette
hypothèse, `J_CC_CTRL` restera utile mais nécessitera une petite interface
adaptatrice ; le trajet de puissance et l'alimentation auxiliaire ne changent
pas.

## Contrôles mécaniques rapides du Beetle

Les cotes officielles suffisent pour la CAO. Avant fabrication, mesurer une fois
sur le module physique : 20,5 × 25,0 mm, rangées à 17,78 mm, pas de 2,54 mm,
trous proches de Ø0,90 mm et orientation USB-C/antenne. Faire aussi un essai à
blanc avec les broches mâles et sockets 1 × 8 retenus.

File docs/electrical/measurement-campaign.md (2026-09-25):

# Campagne de mesures avant schéma définitif

Cette campagne sert à transformer les hypothèses issues des photos et du code en
entrées de conception vérifiées. Les mesures de résistance et de continuité se
font hors tension. Les mesures sous tension doivent commencer avec une source
limitée en courant et sans connecter la BLUETTI tant que les polarités et limites
ne sont pas confirmées.

## Photos et références

- [ ] recto et verso de la Beetle, sérigraphie lisible ;
- [ ] dessus du module ACS712 et marquage du circuit ;
- [ ] valeurs ou marquages précis des résistances du pont diviseur ;
- [ ] recto et verso du buck, inscriptions et référence du contrôleur visibles ;
- [ ] gros plan sur les fils reliant le DFR0520 au buck ;
- [ ] vue complète du chemin des gros fils rouges et de leurs polarités.

## Mesures hors tension

- [ ] continuité entre négatif du redresseur et IN- du buck ;
- [ ] continuité entre IN- et OUT- du buck ;
- [ ] continuité entre OUT- et GND de l'ESP32 ;
- [ ] identification des bornes A, W et B du réglage CC ;
- [ ] résistance A-B du potentiomètre CC ;
- [ ] résistances A-W et W-B aux positions minimum, milieu et maximum ;
- [ ] bornes PA/PW/PB réellement utilisées sur le DFR0520 ;
- [ ] mode exact du fusible et emplacement dans la chaîne.

## Mesures sous tension, sans pédalage

- [ ] tension d'alimentation réelle de la Beetle ;
- [ ] tension d'alimentation réelle du DFR0520 ;
- [ ] tension d'alimentation réelle de l'ACS712 ;
- [ ] sortie de l'ACS712 à zéro courant ;
- [ ] tensions des bornes CC du buck par rapport à IN- ;
- [ ] mêmes tensions par rapport à OUT- ;
- [ ] comportement de la commande CC si le DFR0520 est débranché ;
- [ ] comportement au reset et à la mise sous tension de l'ESP32.

## Validation de l'alimentation auxiliaire

Ces essais seront réalisés sur alimentation de laboratoire limitée en courant,
avant toute connexion à la génératrice ou à un ordinateur :

- [ ] démarrage du convertisseur auxiliaire à 10 V et établissement du 5 V ;
- [ ] régulation du 5 V aux tensions d'entrée représentatives jusqu'à 60 V ;
- [ ] consommation à vide et rendement à 100, 400 et 600 mA ;
- [ ] courant d'appel permettant de sélectionner `F_AUX` sans déclenchement
      intempestif ;
- [ ] température du LM5164, de l'inductance et des condensateurs ;
- [ ] seuils `EN/UVLO` et comportement de `PGOOD` ;
- [ ] tension résiduelle côté générateur lorsque seul l'USB alimente le Beetle ;
- [ ] absence de retour de courant avec `JP_GEN_5V` ouvert ;
- [ ] comportement avec `JP_GEN_5V` fermé et USB volontairement absent ;
- [ ] bascule générateur vers batterie lorsque l'entrée auxiliaire disparaît ;
- [ ] courant de charge réel et température de la batterie 801350 / 500 mAh ;
- [ ] démarrage automatique en pédalant avec batterie déconnectée ;
- [ ] état de la commande CC avant, pendant et après l'initialisation du MCU.

Ne pas réaliser un essai générateur + USB simultané avant validation de
l'isolation. La batterie utilisée devra posséder une protection intégrée et une
fiche autorisant le courant de charge mesuré.

## Mesures en fonctionnement

Pour chaque point, noter la cadence ou la vitesse de génératrice, la position du
potentiomètre numérique, l'état de la BLUETTI et la configuration des lampes.

| Essai | RPM/cadence | Wiper | V avant buck | I avant buck | V après buck | I après buck | Température buck | Sensation |
|---|---:|---:|---:|---:|---:|---:|---:|---|
| ralenti | | | | | | | | |
| 30 W annoncé | | | | | | | | |
| 60 W annoncé | | | | | | | | |
| 90 W annoncé | | | | | | | | |
| limite actuelle | | | | | | | | |

Mesurer également :

- [x] tension en charge observée : environ 36 V ;
- [x] pics observés au démarrage rapide : plus de 40 V, valeur exacte à relever ;
- [ ] tension redressée maximale **à vide**, c'est-à-dire génératrice entraînée
      mais sortie électrique déconnectée, à plusieurs cadences sûres ;
- [ ] maximum transitoire relevé avec oscilloscope ou fonction peak-hold adaptée ;
- [ ] courant d'entrée à 200, 300 et 400 W pour décider si la cible 20 A
      continue est nécessaire ou seulement conservatrice ;
- [ ] tension et courant juste avant le point où la résistance semble disparaître ;
- [ ] mêmes valeurs juste après ce point ;
- [ ] comportement avec BLUETTI puis avec charge de dissipation connue ;
- [ ] température du buck et des connecteurs après un effort soutenu ;
- [ ] courant maximal raisonnablement observé et courant cible de conception.

## Décisions produites par ces mesures

La campagne doit permettre de figer :

1. la tension nominale et la surtension à supporter ;
2. le courant maximal, le fusible et le connecteur de puissance ;
3. la valeur, la puissance et le boîtier du shunt ;
4. la stratégie de masse ;
5. la protection de l'INA228 contre les transitoires ;
6. les valeurs et références de l'alimentation auxiliaire 5 V ;
7. le brochage de `J_CC_CTRL` ;
8. la valeur de repli sûre de la résistance ;
9. les limites logicielles de tension, courant, puissance et température.

Les résultats, les propositions de composants et les calculs 400 W sont
consolidés dans
[`power-path-dimensioning.md`](./power-path-dimensioning.md).

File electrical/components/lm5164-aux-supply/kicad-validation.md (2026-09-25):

# Validation KiCad du LM5164 DDA

Statut : **LM5164DDAT retenu ; symbole standard KiCad validé ; variante locale
V1 à six vias thermiques de 0,30 mm créée, affectée à U4 et validée sans erreur
DRC dans un PCB jetable**.

## Sources

| Élément | Source | Détail utilisé |
|---|---|---|
| Fiche fabricant | `ti-lm5164-snvsa-u4d.pdf` | `SNVSAU4D`, février 2026 |
| Brochage | fiche TI, page PDF 3 | figure 4-1 et table 4-1, vue de dessus |
| Boîtier | fiche TI, pages PDF 28 à 30 | dessin `DDA0008B`, land pattern et stencil |
| Références commandables | fiche TI, page PDF 34 | `DDAT` 250 pièces, `DDAR` 2500 pièces |
| Modèles CAO fabricant | page produit TI | lien TI vers Ultra Librarian, formats KiCad v6+ disponibles |
| Bibliothèque locale | KiCad 10 installé | symbole et footprints inspectés en lecture seule |

Le SHA-256 et l'URL officielle de la fiche archivée sont consignés dans le
[`README.md`](./README.md).

## Référence physique étudiée

- composant : Texas Instruments LM5164 ;
- boîtier : `DDA`, dessin mécanique `DDA0008B`, HSOIC/PowerPAD 8 broches ;
- proposition pour les prototypes : `LM5164DDAT`, même silicium et même boîtier
  que `LM5164DDAR`, mais petite bande de 250 au lieu d'une bobine de 2500 ;
- la proposition `DDAT` reste à confirmer avant de la figer dans la BOM.

## Correspondance des broches

La figure TI est une **vue de dessus**. Les broches 1 à 4 descendent le côté
gauche depuis le repère de broche 1 ; les broches 5 à 8 remontent le côté droit.
Le pad exposé est désigné `9` dans le dessin mécanique et doit être relié à GND,
bien qu'il n'ait aucune connexion électrique interne.

| Broche TI | Fonction TI | Pin du symbole KiCad | Type KiCad observé | Pad attendu |
|---:|---|---:|---|---:|
| 1 | GND | 1 / GND | power input | 1 |
| 2 | VIN | 2 / VIN | power input | 2 |
| 3 | EN/UVLO | 3 / EN/UVLO | input | 3 |
| 4 | RON | 4 / RON | passive | 4 |
| 5 | FB | 5 / FB | input | 5 |
| 6 | PGOOD, sortie open-drain | 6 / PGOOD | open collector | 6 |
| 7 | BST | 7 / BST | passive | 7 |
| 8 | SW | 8 / SW | power output | 8 |
| 9 | EP, pas de connexion interne, à relier à GND | 9 / EP | passive | 9 |

Bilan des nombres : 8 pattes + 1 pad exposé fabricant, 9 pins électriques dans
le symbole KiCad, pads 1 à 8 + pad 9 éventuellement répété pour les vias
thermiques dans le footprint. Les répétitions du numéro 9 sont intentionnelles.

## Symbole KiCad installé

Le symbole existe déjà :

```text
Regulator_Switching:LM5164DDA
```

Son brochage correspond à la table TI. Il n'y a donc aucune raison de recréer
un symbole projet. Son champ footprint pointe actuellement vers :

```text
Package_SO:HSOP-8-1EP_3.9x4.9mm_P1.27mm_EP2.41x3.1mm_ThermalVias
```

Cette association automatique ne vaut pas validation mécanique.

## Comparaison du footprint par défaut

Le footprint installé présente notamment :

- corps nominal 3,9 × 4,9 mm et pas de 1,27 mm ;
- huit pads de 1,60 × 0,60 mm, rangés à `x = ±2,65 mm` ;
- pad exposé de 2,41 × 3,10 mm ;
- six vias thermiques de perçage 0,20 mm ;
- description faisant référence au ST L5973D, et non directement au LM5164.

Le land pattern TI révisé en 2026 indique :

- huit lands de 1,55 × 0,60 mm ;
- pas de 1,27 mm et entraxe de rangées de 5,4 mm, soit `x = ±2,70 mm` ;
- métal du pad exposé de 2,71 × 3,40 mm ;
- vias optionnels de diamètre 0,20 mm ;
- taille du métal susceptible d'être adaptée aux exigences de ligne de fuite.

Les écarts sur les pads latéraux sont faibles, mais le pad thermique par défaut
est inférieur de 0,30 mm dans chaque axe à la recommandation TI actuelle. La
description provenant d'un autre composant empêche de l'accepter par simple
analogie.

Le footprint historique `Package_SO:TI_SO-PowerPAD-8_ThermalVias` est également
présent, mais sa géométrie vient d'une autre fiche TI et ne doit pas être retenue
sans la même comparaison détaillée.

## Audit du paquet proposé par TI

Le paquet téléchargé le 24 septembre 2026 est conservé localement dans :

```text
electrical/kicad/download/ul_LM5164DDAR/
```

Il contient un symbole et quatre footprints, mais aucun fichier STEP. Son
symbole reprend correctement les neuf pins. Il n'apporte toutefois aucun
avantage sur le symbole standard KiCad et utilise plusieurs types de pins
`unspecified` moins utiles à l'ERC.

Les footprints ne sont pas acceptables tels quels :

- les fichiers `IPC_B`, `IPC_C` et `MFG` déclarent tous en interne le nom
  `DDA0008E-IPC_A`, ce qui créerait des collisions ou une sélection trompeuse ;
- les variantes IPC n'ont ni `F.CrtYd` ni vias thermiques ;
- leur pad exposé mesure seulement 2,025 × 3,10 mm ;
- la variante `MFG` numérote les six vias thermiques de 10 à 15 au lieu de leur
  donner le numéro électrique 9 : ils ne seraient donc pas automatiquement
  reliés au pad exposé et à GND ;
- la variante `MFG` utilise un pad cuivre 2,95 × 4,90 mm, mais sans la définition
  de masque 2,71 × 3,40 mm du land pattern TI actuel ;
- aucun des quatre footprints ne contient de modèle 3D.

Hashes SHA-256 des fichiers électriques reçus :

| Fichier | SHA-256 |
|---|---|
| `2026-09-24_14-56-52.kicad_sym` | `2A9FCCB3A7269095B1B9E39BD30CCF5EA773A0BA56808F4D4674823EBB784E28` |
| `DDA0008E-IPC_A.kicad_mod` | `B306C296C3673E55C947E3D49E2407647C8E338BAB3256AE5C468799E03203C1` |
| `DDA0008E-IPC_B.kicad_mod` | `371293F031BC82E934DC4BF0D780C38C5DE6EAF29AA1560158404C9E6B022E0C` |
| `DDA0008E-IPC_C.kicad_mod` | `798B07EF89449A4D70C94E934DDA374FDE0EE1782EF097807F0BE11347BA237B` |
| `DDA0008E-MFG.kicad_mod` | `39319E2B87051C480B49AB5E38548F64EDF46428BC036736BE3C421C3C6E7D8C` |

Le paquet Ultra Librarian est donc une preuve que des modèles sont proposés,
mais il ne doit pas être importé dans le projet.

Un second export a été effectué en choisissant explicitement le symbole
séquentiel, les unités métriques et `DDA0008E-MFG`. Malgré ces choix, le contenu
électrique obtenu est **strictement identique octet pour octet** au premier
paquet :

- le symbole conserve `DDA0008E-IPC_A` dans son champ footprint ;
- les quatre footprints conservent le nom interne `DDA0008E-IPC_A` ;
- les vias de la variante `MFG` restent numérotés 10 à 15 ;
- aucun STEP n'est inclus.

Ce résultat rend le défaut reproductible et exclut une simple erreur de
sélection lors du premier téléchargement.

Un troisième téléchargement, cette fois pour `LM5164DDAT`, contient le modèle
3D `DDA0008E.stp`. Il est conservé comme aide visuelle uniquement :

| Fichier | SHA-256 | Usage |
|---|---|---|
| `DDA0008E.stp` | `61303330D3383C2A1001C5C56C8834EB66A39135D1D5EF496A460EE145437484` | contrôle 3D, pas preuve des pads |

Le fichier indique une génération Creo datée du 10 juin 2024. Il pourra être
associé plus tard à une empreinte projet si la vue 3D est nécessaire. Le symbole
Ultra Librarian `LM5164DDAT` n'est pas importé : son brochage n'apporte rien au
symbole standard, plusieurs types de pins sont moins précis et son champ
footprint pointe encore vers `DDA0008E-IPC_A`.

## Meilleur footprint existant dans KiCad 10

Une seconde recherche dans les bibliothèques installées a trouvé une empreinte
plus récente et explicitement dérivée du dessin TI `DDA0008B` :

```text
Package_SO:SOIC-8-1EP_3.9x4.9mm_P1.27mm_EP2.95x4.9mm_Mask2.71x3.4mm_ThermalVias
```

Elle présente :

- pads 1 à 8 au pas de 1,27 mm, largeur 0,60 mm ;
- extrémité extérieure des pads à ±3,45 mm, comme le land pattern TI ;
- cuivre frontal du pad 9 de 2,95 × 4,90 mm ;
- ouverture de masque dédiée de 2,71 × 3,40 mm ;
- huit vias thermiques de perçage 0,20 mm, tous numérotés 9 ;
- cuivre arrière de dissipation relié au pad 9 ;
- `F.Fab`, `F.SilkS`, repère de pin 1 et `F.CrtYd` complets ;
- quatre ouvertures de pâte segmentées plutôt qu'une ouverture pleine.

Les pads latéraux sont calculés selon une règle IPC et mesurent 1,775 mm de long
au lieu des 1,55 mm de l'exemple TI. Leur bord externe est identique ; ils
s'étendent davantage vers le boîtier. Cette différence facilite la soudure et
reste cohérente avec l'enveloppe mécanique, mais doit être acceptée comme choix
de conception et non présentée comme une copie exacte du dessin fabricant.

Le footprint référence un STEP portant le même nom, mais ce fichier 3D n'est pas
présent dans l'installation locale actuelle. Cela ne remet pas en cause les
pads ; le modèle 3D reste une vérification visuelle optionnelle à compléter.

## Décision de CAO retenue

1. Utiliser la référence commandable `LM5164DDAT`.
2. Conserver le symbole standard `Regulator_Switching:LM5164DDA` et affecter
   `LM5164DDAT` à son champ `Value`.
3. Rejeter les symboles et footprints Ultra Librarian reçus sans les importer.
4. Utiliser comme référence géométrique le footprint standard KiCad
   explicitement basé sur `DDA0008B` :
   `Package_SO:SOIC-8-1EP_3.9x4.9mm_P1.27mm_EP2.95x4.9mm_Mask2.71x3.4mm_ThermalVias`.
5. Utiliser pour la V1 la variante locale explicitement autorisée :
   `BikeGenerator:SOIC-8-1EP_DDA_EP2.95x4.9mm_6Vias_D0.30mm`.
6. Conserver le STEP Ultra Librarian pour la vue 3D, sans l'utiliser comme
   preuve dimensionnelle.

## Relecture structurée Konnect

La relecture du 24 septembre 2026 confirme directement dans les bibliothèques
KiCad 10 installées :

- symbole `Regulator_Switching:LM5164DDA` : 9 pins, numérotées 1 à 9, avec les
  noms et types attendus (`GND`, `VIN`, `EN/UVLO`, `RON`, `FB`, `PGOOD`, `BST`,
  `SW`, `EP`) ;
- footprint retenu : 8 pads latéraux de 1,775 × 0,60 mm au pas de 1,27 mm ;
- pad 9 frontal de 2,95 × 4,90 mm, masque dédié de 2,71 × 3,40 mm et cuivre
  arrière de 1,80 × 4,40 mm ;
- huit vias thermiques traversants de perçage 0,20 mm, tous numérotés 9 ;
- présence de `F.Fab`, `F.SilkS`, `F.CrtYd`, du repère de pin 1 et d'un modèle
  3D déclaré par la bibliothèque.

Cette relecture provient du fichier standard résolu sous
`C:\Program Files\KiCad\10.0\share\kicad\footprints\Package_SO.pretty\` et non
d'un cache Ultra Librarian ou d'une bibliothèque projet.

## Validation dans le PCB jetable

Un projet jetable a été créé dans :

```text
electrical/kicad/exports/lm5164-validation/
```

Le symbole y a été placé avec `Value = LM5164DDAT` et le footprint standard
retenu comme référence géométrique. La relecture de l'instance confirme les
neuf pins et le rendu du symbole montre la vue fonctionnelle attendue : VIN,
EN/UVLO et RON à gauche ; BST, SW, FB et PGOOD à droite ; GND et EP en bas.

Le footprint a ensuite été placé à `(100 mm, 100 mm)` dans le PCB jetable et
entouré d'un contour temporaire de 20 × 20 mm. La relecture du fichier fermé par
Konnect confirme :

- huit pads latéraux 1 à 8 au pas de 1,27 mm ;
- pad exposé 9, ouverture de masque dédiée, cuivre arrière et huit vias tous
  affectés au même numéro 9 ;
- quatre fenêtres de pâte segmentées ;
- repère de broche 1, `F.SilkS`, `F.Fab` et `F.CrtYd` présents.

Le rendu supérieur généré par KiCad confirme visuellement le repère de broche 1,
le sens des deux rangées, la segmentation de pâte et les vias thermiques. Il ne
montre aucun corps 3D : le footprint déclare un STEP standard absent de
l'installation locale. Le STEP Ultra Librarian reste donc une aide visuelle
optionnelle, sans effet sur la validation du cuivre.

Le DRC du PCB jetable donne huit erreurs identiques : chaque via thermique a un
perçage de 0,20 mm, inférieur au minimum de 0,30 mm défini par les contraintes
actuelles. Les autres avertissements proviennent du caractère volontairement
isolé du test : le footprint a été placé directement pour l'inspection et n'a
pas été synchronisé avec le symbole ni raccordé à des nets.

Conclusion historique : la correspondance boîtier, pins, pads, masque et pâte
du footprint standard est validée, mais ses vias de 0,20 mm sont incompatibles
avec la règle V1. Cette empreinte standard reste la référence géométrique ; elle
n'est plus celle affectée à U4.

## Variante locale V1 à perçages de 0,30 mm

Après accord explicite, la variante suivante a été créée dans la bibliothèque
projet `BikeGenerator.pretty` et affectée à `U4` :

```text
BikeGenerator:SOIC-8-1EP_DDA_EP2.95x4.9mm_6Vias_D0.30mm
```

Tous les éléments suivants sont conservés depuis le footprint KiCad relu :

- pads latéraux 1 à 8 : 1,775 × 0,60 mm, pas de 1,27 mm ;
- cuivre frontal du pad 9 : 2,95 × 4,90 mm ;
- ouverture de masque dédiée : 2,71 × 3,40 mm ;
- cuivre arrière du pad 9 : 1,80 × 4,40 mm ;
- quatre ouvertures de pâte de 1,09 × 1,37 mm, centrées à
  `x = ±0,68 mm`, `y = ±0,85 mm` ;
- géométries `F.Fab`, `F.SilkS`, repère de pin 1 et `F.CrtYd` ;
- tous les éléments cuivre thermiques portent le numéro électrique 9.

Le réseau thermique V1 comprend six vias traversants :

| Paramètre | Valeur retenue |
|---|---:|
| Matrice | 2 colonnes × 3 rangées |
| Centres X | `−0,55 mm`, `+0,55 mm` |
| Centres Y | `−1,30 mm`, `0 mm`, `+1,30 mm` |
| Diamètre cuivre | 0,60 mm |
| Perçage métallisé | 0,30 mm |
| Anneau annulaire radial | 0,15 mm |
| Pas horizontal / espace cuivre | 1,10 mm / 0,50 mm |
| Pas vertical / espace cuivre | 1,30 mm / 0,70 mm |

Les bords des vias restent à 0,05 mm au minimum à l'intérieur du cuivre
arrière, à 0,10 mm à l'intérieur de l'ouverture de masque et avec une marge
supérieure sur le cuivre frontal. La règle du projet exige un perçage minimal
de 0,30 mm, une taille de via minimale de 0,50 mm et un espacement trou à trou
minimal de 0,25 mm ; la variante respecte ces trois limites.

Une seconde carte jetable a été créée dans :

```text
electrical/kicad/exports/lm5164-validation-030/
```

Elle place la variante locale dans un contour de 20 × 20 mm. Le rapport
`drc.json` donne :

- 0 erreur ;
- 0 violation de règle de conception ;
- 0 élément non connecté ;
- 1 avertissement `extra_footprint`, attendu parce que cette carte isolée ne
  possède volontairement pas de schéma associé.

Le risque thermique accepté pour cette V1 reste distinct du résultat DRC : six
vias évacuent probablement un peu moins de chaleur que les huit vias de 0,20 mm
du footprint de référence. Une montée en température pouvant conduire à la
protection thermique du LM5164 est acceptée comme risque de prototype, mais ne
constitue pas un mode nominal. La température devra être mesurée pendant les
essais à charge croissante.

## Clarification : « 0,20 mm contre 0,30 mm »

Il ne s'agit pas de choisir entre des **pads** de 0,20 et 0,30 mm. Trois objets
différents interviennent :

1. le grand pad exposé `EP`/9 sous le LM5164, qui évacue la chaleur et relie le
   boîtier à GND ;
2. les petits pads annulaires des vias thermiques, c'est-à-dire le cuivre autour
   de chaque trou ;
3. le perçage métallisé de ces vias.

Deux valeurs de 0,30 mm sont apparues dans l'analyse, sans désigner la même
chose :

- l'ancien footprint par défaut avait un grand pad thermique inférieur de
  **0,30 mm dans chaque axe** au land pattern TI actuel. Ce problème est réglé :
  ce footprint a été rejeté ;
- le footprint standard finalement retenu possède huit **perçages de via de
  0,20 mm**, tandis que la règle DRC actuelle impose un perçage minimal de
  **0,30 mm**. Ce second point reste ouvert et produit huit erreurs DRC.

### Pourquoi conserver 0,20 mm

- c'est le diamètre optionnel indiqué par le dessin TI ;
- huit petits vias tiennent facilement sous le pad exposé ;
- les trous plus petits limitent la quantité de pâte aspirée pendant la refusion ;
- on conserve sans modification le footprint standard KiCad déjà relu.

Cette solution exige cependant un fabricant garantissant les trous métallisés
finis de 0,20 mm, éventuellement avec un supplément de prix ou des contraintes
de rapport d'aspect.

### Pourquoi passer à 0,30 mm

- compatibilité plus large avec les procédés PCB standards ;
- fabrication et contrôle plus simples pour une première carte ;
- disparition de l'exception DRC si 0,30 mm reste le minimum général du projet.

En contrepartie, il ne suffit pas d'agrandir le trou. Le diamètre du pad de via
doit aussi respecter l'anneau minimal du fabricant :

```text
diamètre_pad_via >= diamètre_perçage + 2 × anneau_minimal
```

Par exemple, avec un trou de 0,30 mm et un anneau exigé de 0,15 mm, le pad doit
faire au moins 0,60 mm. Il faut ensuite vérifier que huit pads de ce diamètre
tiennent sous le pad thermique avec les espacements requis. Sinon, une matrice
de six vias de 0,30 mm peut être préférable. Les trous plus grands augmentent
aussi le risque d'aspiration de soudure ; le procédé de bouchage, remplissage ou
tente des vias doit être défini avec l'assembleur.

### Décision appliquée pour cette V1

La règle DRC globale n'a pas été abaissée. La variante projet à six vias
Ø0,60/0,30 mm décrite ci-dessus est appliquée à U4 et passe le DRC. Avant la
commande, il reste à confirmer auprès du fabricant l'anneau de 0,15 mm, le
traitement des vias sous pad et les contraintes de pâte afin de limiter
l'aspiration de soudure.

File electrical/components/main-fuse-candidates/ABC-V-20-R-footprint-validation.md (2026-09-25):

# Validation de l'empreinte Eaton ABC-V-20-R

## Sources

- page produit Eaton `ABC-V-20-R`, consultée le 25 septembre 2026 :
  <https://www.eaton.com/us/en-us/skuPage.ABC-V-20-R.html>
- fiche Eaton série ABC, publication 2000, révision effective novembre 2021 :
  <https://www.eaton.com/content/dam/eaton/products/electronic-components/resources/data-sheet/eaton-abc-fast-acting-ceramic-tube-fuses-data-sheet.pdf>
- dessin mécanique historique de la même série ABC/ABC-V, utilisé pour relever
  les tolérances maximales du boîtier et le diamètre des fils ; la page produit
  Eaton actuelle confirme l'enveloppe hors tout de la version axiale.

## Correspondance physique

| Élément | Donnée fabricant | Géométrie KiCad |
|---|---:|---:|
| corps maximal | 32,82 × 6,76 mm | `F.Fab` 32,82 × 6,76 mm |
| diamètre des fils, version 20 A | 1,02 mm | perçage fini 1,30 mm |
| entraxe de montage | non imposé par Eaton, fils formables | 38,10 mm |
| pads | choix de conception | 4,00 × 5,00 mm, THT |
| courtyard | choix IPC/projet | 43,10 × 7,76 mm, soit 0,50 mm autour de l'enveloppe pads/corps |

L'entraxe de 38,10 mm est donc un **choix de montage de la carte**, pas une cote
de land pattern recommandée par Eaton. Il laisse 2,64 mm de fil horizontal de
chaque côté du corps maximal avant le coude. Les trous de 1,30 mm laissent
0,28 mm de jeu diamétral autour des fils nominaux de 1,02 mm. Les grands pads
favorisent la soudure manuelle et le raccordement au cuivre 20 A ; ils ne
dispensent pas du calcul des pistes, des plans et des éventuels renforts.

## Vérifications ECAD du 25 septembre 2026

- recherche KiCad : aucune empreinte exacte `ABC-V-20-R` ;
- pads : 1 et 2 présents, traversants, non polarisés, perçage 1,30 mm ;
- entraxe : 38,10 mm ;
- `F.Fab` : enveloppe maximale 32,82 × 6,76 mm et fils jusqu'aux pads ;
- `F.SilkS` : contour du corps sans recouvrir les pads ;
- `F.CrtYd` : 43,10 × 7,76 mm ;
- modèle 3D : absent, volontairement ;
- PCB : `F1` à `(43,00 ; 127,00)`, pads à `(23,95 ; 127,00)` et
  `(62,05 ; 127,00)` ;
- score de placement Konnect : 100/100, sans chevauchement de courtyard et
  sans composant hors contour.

L'empreinte locale se trouve dans
`electrical/kicad/libraries/footprints/BikeGenerator.pretty/`.

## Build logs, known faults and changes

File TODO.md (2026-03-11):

# TODO

---

## Hardware

- [x] Wire voltage divider (R1=100kΩ, R2=7.5kΩ, bus → GPIO1)
- [x] Calibrate `VDIV_OFFSET_V` against multimeter reading
- [x] Verify stable power reading end-to-end (V × I = W on serial)

---

## Firmware

- [x] Run calibration procedure with voltage divider connected (update `POT_CAL_POWER`)
- [x] Test all 3 modes with Zwift: Manual, ERG, Simulation
- [x] Test EnOcean button disconnected / reconnected while app is live
- [x] Verify 200W ceiling holds (2× halogen pairs + BLUETTI)
- [x] Replace heuristic speed model with proper physics (Newton's method, CdA/Crr)

---

## V2 Hardware — Real Speed + Better Climb Feel

> Current limitation: speed is *computed* from power via physics model, not measured.
> This creates a circular dependency (grade → resistance → power → speed → grade)
> and means resistance softens naturally as cadence drops — the opposite of a real climb.

- [ ] **Add hall effect sensor for real wheel speed**
  - Parts: A3144 sensor + 2× neodymium disc magnets (6×2mm) + 10kΩ resistor (~€3)
  - Magnets zip-tied to spokes near rim; sensor zip-tied to chainstay, gap 2–3mm
  - Wire: VCC→3.3V, GND→GND, OUT→GPIO3 + 10kΩ pullup
  - Formula: `speed = (circumference / n_magnets) / pulse_interval × 3.6`
  - Use `WHEEL_CIRCUMFERENCE_M = 2.07` for 700c wheel, `SPEED_MAGNETS = 2`
  - Implement as interrupt on falling edge, same pattern as cadence sensor

- [ ] **Closed-loop grade control once speed is real**
  - With measured speed, compute required power physics: `P = (Crr·m·g + m·g·grade + ½·ρ·CdA·v²) × v`
  - Use that as dynamic ERG target, updated every control loop tick
  - When rider slows on a climb → target power increases → digipot compensates for generator RPM drop
  - **Effect:** resistance chases you as you slow — gravity-like behavior instead of softening load

- [ ] **V3: eddy current brake for low-RPM floor** *(longer term)*
  - Generator torque drops to near-zero at very low RPM — software can't compensate beyond its physical limit
  - Eddy brake (electromagnet + copper disk on axle, controlled via PWM) adds speed-independent braking force
  - Stack with generator: generator handles main load, eddy brake provides the "gravity floor" at slow cadence
  - This is what mid-range smart trainers (Tacx Flux, Wahoo Kickr Snap) do internally

- [ ] **Flywheel for inertia feel** *(optional, separate from grade accuracy)*
  - Weighted flywheel on the generator shaft gives coast-and-momentum feel
  - No electronics needed — pure mechanical improvement to perceived realism

---

## Documentation / Tutorial

- [ ] Add real photos to `build-tutorial.md` (14 photo placeholders marked)
- [ ] Add photo of CC trim pot location on buck module (most critical image)
- [ ] Add photo of electronics box interior
- [ ] Add wiring diagram image (`docs/images/power-path.png`)
- [ ] Review tutorial with a fresh reader before publishing

---

## Hackathon (deadline: March 25)

- [ ] Bike physically ready and stable for student use
- [ ] Print / share `docs/ble-api.md` with students on Day 1
- [ ] Brief intro session: what the bike sends, what they can control, live demo
- [ ] Confirm students can connect (test with one laptop / phone before event)

---

## Communication

- [ ] Write project page text (website)
- [ ] Draft short punchy pitch (1 paragraph for social / talks)
- [ ] Document the hackathon: photos/video during the event
- [ ] Post-event write-up: what the students built with it

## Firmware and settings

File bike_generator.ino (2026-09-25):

/**
 * @file main.ino
 * @brief ESP32-C3 Bike Generator / Smart Trainer - Modular Implementation
 * 
 * Human-powered energy system + "smart trainer" feel
 * Compatible with: Zwift, GoldenCheetah, TrainerRoad, Rouvy
 * 
 * Hardware: ESP32-C3 Beetle + current/power sensing + MCP4151-104 + energy sink
 */

#include "config.h"
#include "hardware.h"
#include "sensors.h"
#include "resistance.h"
#include "ble_ftms.h"
#include "physics.h"
#include "control_modes.h"
#include "button_scanner.h"
#include "utils.h"

// Global state
static BikeData bikeData = {0, 0, 0};
static float currentCadence = 70.0f;

// Button callback
void onButtonPress(bool isPlus) {
  if (isPlus) {
    Resistance_Increase();
    Serial.println("[BUTTON] PLUS pressed");
  } else {
    Resistance_Decrease();
    Serial.println("[BUTTON] MINUS pressed");
  }
}

// Update bike data
void updateBikeData() {
  static unsigned long lastUpdate = 0;
  
  if (millis() - lastUpdate < BIKE_DATA_UPDATE_MS) return;
  lastUpdate = millis();
  
  // Read sensors
  Sensors_Update();
  SensorData sensors = Sensors_GetAll();
  
  // Update resistance if app is connected
  if (FTMS_IsConnected()) {
    ControlMode_UpdateResistance();
  }
  
  // Get current grade
  float gradePercent = 0.0f;
  if (ControlMode_Get() == MODE_SIMULATION) {
    gradePercent = ControlMode_GetSimulationGrade() / 100.0f;
  }
  
  // Calculate speed and cadence
  float speed = Physics_CalculateSpeed(sensors.power, gradePercent);
  bikeData.instantaneousSpeed = (uint16_t)(speed * 100);
  
  currentCadence = Physics_CalculateCadence(sensors.power, gradePercent, currentCadence);
  bikeData.instantaneousCadence = (uint16_t)(currentCadence * 2);
  
  bikeData.instantaneousPower = (int16_t)sensors.power;
  if (bikeData.instantaneousPower < 0) bikeData.instantaneousPower = 0;
}

// Status logging
void logStatus() {
  static unsigned long lastLog = 0;
  
  if (millis() - lastLog < STATUS_LOG_INTERVAL_MS) return;
  lastLog = millis();
  
  SensorData sensors = Sensors_GetAll();
  
  Serial.println("\n========== STATUS DUMP ==========");
  
  Serial.print("Mode:     ");
  ControlMode mode = ControlMode_Get();
  switch(mode) {
    case MODE_MANUAL:
      Serial.printf("MANUAL (resistance: %d/100)\n", ControlMode_GetResistanceLevel());
      break;
    case MODE_ERG:
      Serial.printf("ERG\n");
      Serial.printf("Target:   %dW\n", ControlMode_GetTargetPower());
      break;
    case MODE_SIMULATION:
      Serial.printf("SIMULATION\n");
      Serial.printf("Grade:    %.1f%%\n", ControlMode_GetSimulationGrade() / 100.0);
      break;
  }
  
  Serial.printf("Power:    %.1fW (V=%.2fV, I=%.3fA)\n", 
                sensors.power, sensors.voltage, sensors.current);
  Serial.printf("ADC curr: Raw=%d, Vpin=%.3fV\n", 
                sensors.rawADC, sensors.adcVoltage);
  Serial.printf("ADC volt: Vpin=%.3fV → bus=%.2fV (divider x%.2f)\n",
                sensors.adcVoltageDivider, sensors.voltage, VDIV_SCALE);
  
  int digipot = Resistance_Get();
  Serial.printf("Digipot:  %d/%d (%.0f%% = ~%.0fW)\n", 
                digipot, POT_SAFE_MAX,
                (digipot / (float)POT_SAFE_MAX) * 100.0f,
                digipot / POT_WATTS_TO_WIPER_SLOPE);
  
  Serial.printf("Speed:    %.1f km/h\n", bikeData.instantaneousSpeed / 100.0);
  Serial.printf("Cadence:  %d RPM\n", bikeData.instantaneousCadence / 2);
  
  Serial.println("=================================\n");
}

void setup() {
  Serial.begin(115200);
  delay(2000);
  
  Serial.println("\n\n========================================");
  Serial.println("  ESP32-C3 FTMS Indoor Bike Trainer");
  Serial.println("  Modular Open Source Version");
  Serial.println("========================================\n");
  
  // Initialize all modules
  Hardware_Init();
  Sensors_Init();
  Resistance_Init();
  ControlMode_Init();
  FTMS_Init();
  FTMS_Start();
  
  // Initialize button scanner
  ButtonScanner_Init();
  ButtonScanner_SetCallback(onButtonPress);
  ButtonScanner_Start();
  
  Serial.println("\n*** READY TO PAIR ***");
  Serial.println("Device name: '" BLE_DEVICE_NAME "'");
  Serial.println("Open Zwift/GoldenCheetah and scan for devices");
  Serial.println("Waiting for connection...\n");
}

void loop() {
  // Handle BLE connection state changes
  FTMS_HandleConnectionChange();
  
  // Manage button scanning
  static bool wasConnected = false;
  bool isConnected = FTMS_IsConnected();
  
  if (isConnected && !wasConnected) {
    ButtonScanner_Stop();
    Serial.println("[SCAN] Stopped button scanning (app in control)");
  }
  
  if (!isConnected && wasConnected) {
    ButtonScanner_Start();
    Serial.println("[SCAN] Resumed button scanning (manual control)");
  }
  
  wasConnected = isConnected;
  
  // Update button scanner when not connected
  if (!isConnected) {
    ButtonScanner_Update();
  }
  
  // Always update bike data
  updateBikeData();
  
  // Send BLE notifications when connected
  static unsigned long lastNotify = 0;
  if (isConnected && millis() - lastNotify >= BLE_NOTIFY_INTERVAL_MS) {
    lastNotify = millis();
    FTMS_SendBikeData(bikeData);
  }
  
  // Log status
  logStatus();
  
  // Heartbeat: print current BLE state so it's always clear in the log
  {
    static unsigned long lastHeartbeat = 0;
    if (millis() - lastHeartbeat >= HEARTBEAT_INTERVAL_MS) {
      lastHeartbeat = millis();
      if (isConnected) {
        Serial.println("[BLE] << connected — streaming data >>");
      } else {
        Serial.println("[BLE] << not connected — advertising >>");
      }
    }
  }
  
  delay(100);
}

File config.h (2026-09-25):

/**
 * @file config.h
 * @brief Central configuration for Bike Generator/Smart Trainer
 * 
 * All hardware pins, calibration constants, and tuning parameters
 */

#ifndef CONFIG_H
#define CONFIG_H

// ============================================================================
// HARDWARE PIN DEFINITIONS
// ============================================================================

#define PIN_CURRENT_SENSOR  0   // ACS712 30A on GPIO0 (ADC)
#define PIN_VOLTAGE_SENSOR  1   // Voltage divider on GPIO1 (ADC1 ch1)
#define PIN_POT_CS          5   // Digipot Chip Select
#define PIN_POT_SCK         6   // Digipot Clock
#define PIN_POT_MOSI        7   // Digipot MOSI

// ============================================================================
// SENSOR CALIBRATION
// ============================================================================

// ACS712 30A Configuration
#define ACS712_SENSITIVITY      0.039f  // 39 mV/A (calibrated, adjusted +5% from 41mV/A)
#define ADC_AVERAGING_SAMPLES   128     // Number of samples for ADC averaging

// ----------------------------------------------------------------------------
// Voltage divider (resistive) — bus voltage measurement
// ----------------------------------------------------------------------------
// Circuit:  V_BUS ──[R1]──┬──[R2]── GND
//                         └──► GPIO1 (ADC)
//
// Choose R1/R2 so that V_BUS_MAX maps to <= ADC_VREF:
//   V_ADC = V_BUS * R2 / (R1 + R2)
//   R1=100kOhm, R2=7.5kOhm -> ratio=0.0698
//   V_ADC at 40V bus = 2.79V, safely below 3.3V.
//
// To change resistors: update only R1_OHMS and R2_OHMS below.
// All scaling is derived automatically.
#define VDIV_R1_OHMS        100000.0f   // Top resistor (V_BUS side), Ω  — 100kΩ
#define VDIV_R2_OHMS         7500.0f    // Bottom resistor (GND side),  Ω  — 7.5kΩ (safe to 40V)

// ADC reference voltage (ESP32-C3 with ADC_11db attenuation, nominally 3.3V)
// Trim this slightly if your readings are off — measure 3V3 pin with multimeter.
#define ADC_VREF_MV         3300.0f     // millivolts

// Derived constants (do not edit)
#define VDIV_RATIO          (VDIV_R2_OHMS / (VDIV_R1_OHMS + VDIV_R2_OHMS))
#define VDIV_SCALE          (1.0f / VDIV_RATIO)         // multiply ADC voltage → bus voltage
#define VDIV_MAX_BUS_V      (ADC_VREF_MV / 1000.0f * VDIV_SCALE)  // theoretical max measurable (V)

// Software voltage calibration offset — set to 0 initially, trim after measuring a known voltage
#define VDIV_OFFSET_V       0.0f        // additive correction in Volts

// ============================================================================
// DIGITAL POTENTIOMETER (MCP4151-104, single channel, 100kΩ, 257 taps)
// ============================================================================

// MCP4151 16-bit write: AD3:AD0=0000 (volatile wiper 0), C1:C0=00.
// Values used here stay in the preserved 0..255 range, therefore D8=0.
#define MCP4151_CMD_WRITE_WIPER0  0x00

// Single-point hardware calibration (linear through origin assumed).
// HOW TO UPDATE: set wiper to POT_CAL_VALUE, let rider pedal steadily at constant
// cadence, note the stable watt reading → update POT_CAL_POWER.
#define POT_CAL_VALUE       30      // Wiper position used for calibration measurement
#define POT_CAL_POWER       120.0f  // Measured bus power at POT_CAL_VALUE (W)

// Derived slope:  wiper_per_watt = POT_CAL_VALUE / POT_CAL_POWER
// → wiper(P) = P * (POT_CAL_VALUE / POT_CAL_POWER)
// This is identical to the old formula and preserves the same ceiling at wiper=50 for 200W.
#define POT_WATTS_TO_WIPER_SLOPE  ((float)POT_CAL_VALUE / POT_CAL_POWER)

// Hard limits
#define POT_MIN             0       // Minimum wiper
#define POT_MAX             255     // Preserved V1 control range; MCP4151 full-scale code 256 is unused
#define POT_SAFE_MAX        ((int)(HILL_POWER_TARGET * POT_WATTS_TO_WIPER_SLOPE))  // = old POT_MAX (50 at current cal)

// Initial wiper on boot (flat road target)
#define POT_INITIAL         ((int)(FLAT_POWER_TARGET * POT_WATTS_TO_WIPER_SLOPE))

// Button step: ~10 equal steps across usable range (POT_MIN → POT_SAFE_MAX)
#define POT_STEP            ((int)(POT_SAFE_MAX / 10))

// ============================================================================
// ENOCEAN BUTTON (BLE)
// ============================================================================

// Target MAC: E2:15:00:00:61:F1
#define ENOCEAN_MAC_0       0xE2
#define ENOCEAN_MAC_1       0x15
#define ENOCEAN_MAC_2       0x00
#define ENOCEAN_MAC_3       0x00
#define ENOCEAN_MAC_4       0x61
#define ENOCEAN_MAC_5       0xF1

#define BTN_PLUS_MASK       0x08    // byte[6] & 0xFE == 0x08
#define BTN_MINUS_MASK      0x10    // byte[6] & 0xFE == 0x10

// ============================================================================
// PHYSICS SIMULATION PARAMETERS
// ============================================================================
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

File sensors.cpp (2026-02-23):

/**
 * @file sensors.cpp
 * @brief Sensor management implementation
 */

#include "sensors.h"
#include "config.h"
#include "utils.h"

static uint32_t s_midpoint_mV = 0;
static float s_measured_voltage = 0.0f;   // Now read from ADC, no longer hardcoded
static float s_measured_current = 0.0f;
static float s_measured_power = 0.0f;
static int   s_last_adc_raw = 0;
static float s_last_adc_voltage = 0.0f;
static float s_last_adc_voltage_divider = 0.0f;  // raw ADC voltage on voltage pin (debug)

void Sensors_Init() {
  Serial.println("[SENSORS] Initializing...");
  Sensors_Calibrate();
  Serial.println("[SENSORS] Ready");
}

void Sensors_Calibrate() {
  Serial.println("[SENSORS] Calibrating zero point (no current)...");
  delay(1000);
  s_midpoint_mV = Utils_ReadMilliVoltsAvg(PIN_CURRENT_SENSOR, 8192);
  Serial.printf("[SENSORS] ACS712 midpoint: %lu mV (%.3fV)\n", 
                (unsigned long)s_midpoint_mV, s_midpoint_mV / 1000.0f);
}

float Sensors_ReadCurrent() {
  uint32_t mv = Utils_ReadMilliVoltsAvg(PIN_CURRENT_SENSOR, ADC_AVERAGING_SAMPLES);
  float voltage = mv / 1000.0f;
  float midpoint = s_midpoint_mV / 1000.0f;
  
  float dV = voltage - midpoint;
  float current = fabsf(dV / ACS712_SENSITIVITY);
  
  s_last_adc_raw = analogRead(PIN_CURRENT_SENSOR);
  s_last_adc_voltage = voltage;
  s_measured_current = current;
  
  return current;
}

float Sensors_ReadVoltage() {
  // Read ADC, average to reduce noise
  uint32_t mv = Utils_ReadMilliVoltsAvg(PIN_VOLTAGE_SENSOR, ADC_AVERAGING_SAMPLES);

  // Scale from ADC millivolts to actual bus voltage using the divider ratio
  s_last_adc_voltage_divider = mv / 1000.0f;
  float busVoltage = s_last_adc_voltage_divider * VDIV_SCALE + VDIV_OFFSET_V;

  if (busVoltage < 0.0f) busVoltage = 0.0f;

  s_measured_voltage = busVoltage;
  return busVoltage;
}

float Sensors_GetPower() {
  return s_measured_power;
}

SensorData Sensors_GetAll() {
  SensorData data;
  data.voltage              = s_measured_voltage;
  data.current              = s_measured_current;
  data.power                = s_measured_power;
  data.rawADC               = s_last_adc_raw;
  data.adcVoltage           = s_last_adc_voltage;
  data.adcVoltageDivider    = s_last_adc_voltage_divider;
  return data;
}

void Sensors_Update() {
  s_measured_current = Sensors_ReadCurrent();
  s_measured_voltage = Sensors_ReadVoltage();
  s_measured_power = s_measured_voltage * s_measured_current;
  if (s_measured_power < 0) s_measured_power = 0;
}

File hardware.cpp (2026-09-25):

/**
 * @file hardware.cpp
 * @brief Hardware abstraction layer implementation
 */

#include "hardware.h"
#include "config.h"
#include "driver/gpio.h"  // for gpio_set_pull_mode / GPIO_FLOATING

void Hardware_Init() {
  Serial.println("[HW] Initializing hardware...");
  Hardware_SetupADC();
  Hardware_SetupSPI();
  Serial.println("[HW] Hardware initialization complete");
}

void Hardware_SetupADC() {
  analogReadResolution(12);

  // Current sensor (ACS712)
  analogSetPinAttenuation(PIN_CURRENT_SENSOR, ADC_11db);
  pinMode(PIN_CURRENT_SENSOR, INPUT);
  gpio_set_pull_mode((gpio_num_t)PIN_CURRENT_SENSOR, GPIO_FLOATING);  // disable internal pull-up/down (must be last)
  Serial.printf("[HW] Current sensor on GPIO%d (ACS712 30A)\n", PIN_CURRENT_SENSOR);

  // Voltage sensor (resistive divider)
  analogSetPinAttenuation(PIN_VOLTAGE_SENSOR, ADC_11db);
  pinMode(PIN_VOLTAGE_SENSOR, INPUT);
  gpio_set_pull_mode((gpio_num_t)PIN_VOLTAGE_SENSOR, GPIO_FLOATING);  // disable internal pull-up/down (must be last)
  Serial.printf("[HW] Voltage sensor on GPIO%d (divider R1=%.0fk R2=%.0fk, max=%.1fV)\n",
                PIN_VOLTAGE_SENSOR,
                VDIV_R1_OHMS / 1000.0f,
                VDIV_R2_OHMS / 1000.0f,
                VDIV_MAX_BUS_V);
}

void Hardware_SetupSPI() {
  pinMode(PIN_POT_CS, OUTPUT);
  digitalWrite(PIN_POT_CS, HIGH);
  SPI.begin(PIN_POT_SCK, -1, PIN_POT_MOSI, PIN_POT_CS);
  Serial.printf("[HW] MCP4151 SPI (write-only): CS=%d, SCK=%d, MOSI=%d\n",
                PIN_POT_CS, PIN_POT_SCK, PIN_POT_MOSI);
}

int Hardware_GetSPI_CS_Pin() {
  return PIN_POT_CS;
}

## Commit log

2026-03-05 Add voltage divider, cleaner power callculation and speed calculation
2026-03-11 Add Unity support and sample project, retrieve ble info set grade move sphere and display info on gaming view
2026-03-27 Ajout des sprites de Sarah
2026-03-27 Center display and add button for input selection ingame
2026-03-27 Put bike info bottom ledft, add grade %
2026-09-23 docs: explain resistance physics and related projects
2026-09-23 docs: define INA228 electrical PCB v1
2026-09-23 feat: initialize KiCad controller project
    [bike-generator-controller.kicad_pcb, bike-generator-controller.kicad_sch]
2026-09-23 feat: add KiCad schematic hierarchy
    [bike-generator-controller.kicad_sch, cc_control.kicad_sch, connectors.kicad_sch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]
2026-09-23 feat: validate and place INA228
    [ina228_sense.kicad_sch]
2026-09-24 feat: integrate controller modules and schematics
    [bike-generator-controller.kicad_sch, cc_control.kicad_sch, connectors.kicad_sch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]
2026-09-24 docs: specify autonomous controller power
2026-09-24 docs: plan KiCad power integration
2026-09-24 docs: audit LM5164 CAD models
2026-09-24 feat: build provisional power path schematic
    [bike-generator-controller.kicad_sch, power_path.kicad_sch]
2026-09-24 docs: record LM5164 footprint validation
2026-09-24 feat: add LM5164 auxiliary supply schematic
    [aux_supply.kicad_sch, bike-generator-controller.kicad_sch, power_path.kicad_sch]
2026-09-24 feat: add MCU power interlock and battery input
    [bike-generator-controller.kicad_sch, mcu.kicad_sch]
2026-09-25 feat: add provisional JST battery connection
    [mcu.kicad_sch]
2026-09-25 docs: refine power path sizing and measurements
2026-09-25 docs: clarify RF antenna and LM5164 thermal vias
2026-09-25 feat: establish controller PCB V1 design baseline
    [aux_supply.kicad_sch, bike-generator-controller.kicad_pcb, bike-generator-controller.kicad_sch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]
2026-09-25 feat: route primary power and INA228 Kelvin paths
    [bike-generator-controller.kicad_pcb]
2026-09-25 feat: route LM5164 auxiliary supply
    [bike-generator-controller.kicad_pcb]
2026-09-27 wip: capture live PCB state before routing fixes
2026-09-28 docs: detail v2 usb power path
2026-09-28 docs: define v1 and v2 battery controls
2026-09-28 feat: replace v1 battery switch with jumper
2026-09-29 feat(pcb): finalize V1 controller layout
2026-10-13 feat(electrical): checkpoint V2 schematic and complete provisional placement
    Save the pre-routing V2 state, local CAD libraries, BOM, design reviews and routing handoff. 149 footprints, 17 inherited tracks; placement is provisional and not fabrication or energization approval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
